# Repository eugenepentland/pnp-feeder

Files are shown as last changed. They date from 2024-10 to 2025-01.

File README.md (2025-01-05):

# Pick and Place Feeder Project

Prototype Feeder Advancing

## Overview
The aim of this project is to design a low cost powered and addressable pick and place feeder. Other pnp feeders exist but didn't meet my design requirements or were too expensive to justify having 100+ feeders.

This project aims to solve these challenges by providing an easy-to-use, modular, and affordable feeder system that can be used with both the Neoden 4 and Lumen PnP machines.

## Design Goals

1. **Compatibility**
   - Design a powered, pick and place feeder compatible with Neoden 4 and OpenPNP machines.
   - Support component sizes down to 0201.

2. **Low Cost**
   - Keep the BOM cost per feeder unit under $10 to make the solution accessible and affordable for hobbyists and small manufacturers.

3. **Fast Production**
   - Limit 3D printing time per unit to less than 2 hours using a standard consumer-grade 3D printer.
   - Assembly time less than 10 minutes per feeder

4. **Ease of Use**
   - Ensure quick part loading to minimize the setup time.
   - Allow preloaded cartridges for efficient part swapping, avoiding the need to load components directly into the machine.

5. **Scalability**
   - Support up to 512 feeders on a single master device to enable integration into a larger inventory system, such as with InvenTree.

## Block Diagrams

### System Block Diagram
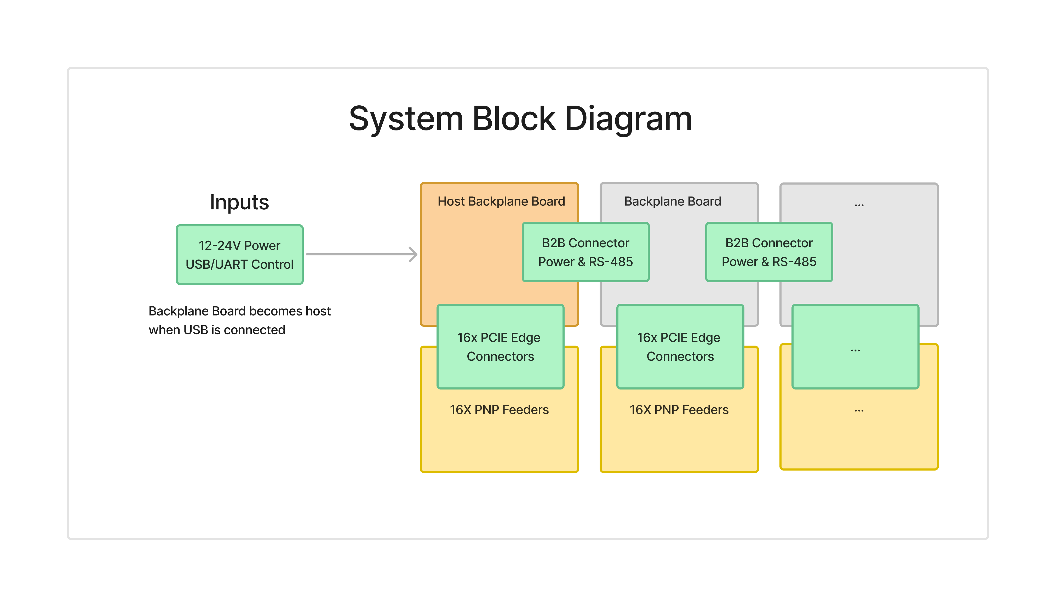
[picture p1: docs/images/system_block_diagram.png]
System Block Diagram


The system block diagram illustrates the two boards involved in the design: the feeder and the backplane board. One backplane board acts as the host, from either being connected to a PC or getting data from the host UART bus. Additional backplane boards can be attached and act as slaves to allow for up to 512 feeders from one host which sends RS-485 data and power. This scalability makes the system suitable for use as an inventory system. Power can be supplied at either 24V or 12V.

### Feeder Block Diagram
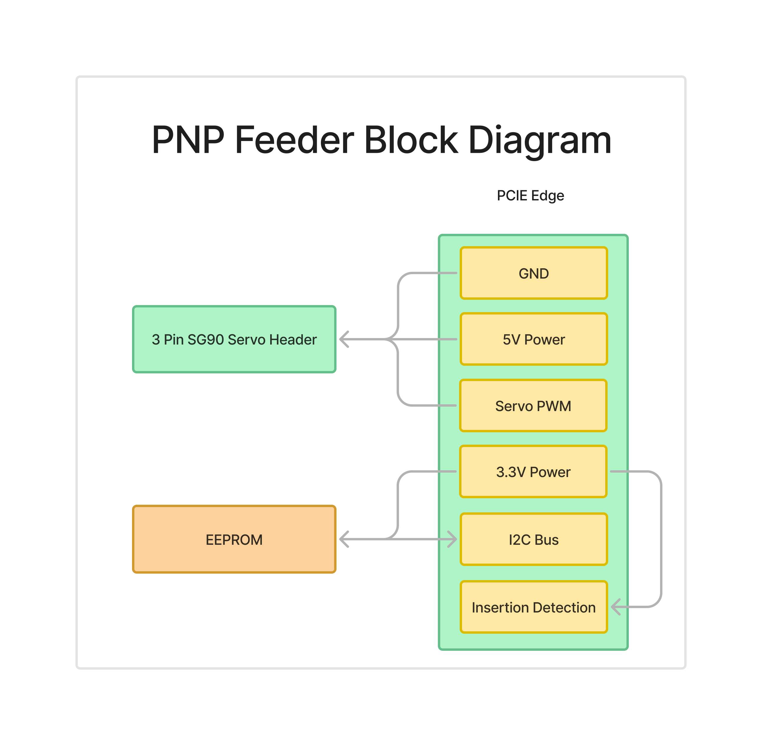
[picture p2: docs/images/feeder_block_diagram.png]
Feeder Block Diagram


The feeder block diagram shows that each feeder has a very simple board, just an EEPROM for storing MPN, quantity, feed distance and any other metadata, as well as a header for the SG90 servo motor., which controls an SG90 servo motor responsible for advancing the tape forwards. 

## Progress Checklist

1. [X] System Level Block Diagram
2. [X] Feeder Block Diagram
3. [X] Backplane Block Diagram
4. [X] MVP Feeder Hardware Prototype
5. [X] Feeder Positioning Accuracy Testing
6. [X] Feeder Lifespan Testing
7. [ ] Neoden 4 Data Packet Reverse Engineering
8. [X] Mechanical Footprint Design
9. [X] Feeder PCB Layout
10. [X] Feeder Schematic
11. [X] Backplane PCB Layout
12. [X] Backplane PCB Schematic
13. [ ] Order PCBs and test
14. [ ] System Integration and Testing
15. [ ] Support OpenPNP

## Contributing
Contributions are welcome! Please check the progress checklist above and feel free to open issues or submit pull requests for any ongoing tasks.

## License
This project is licensed under the MIT License - see the LICENSE file for details.

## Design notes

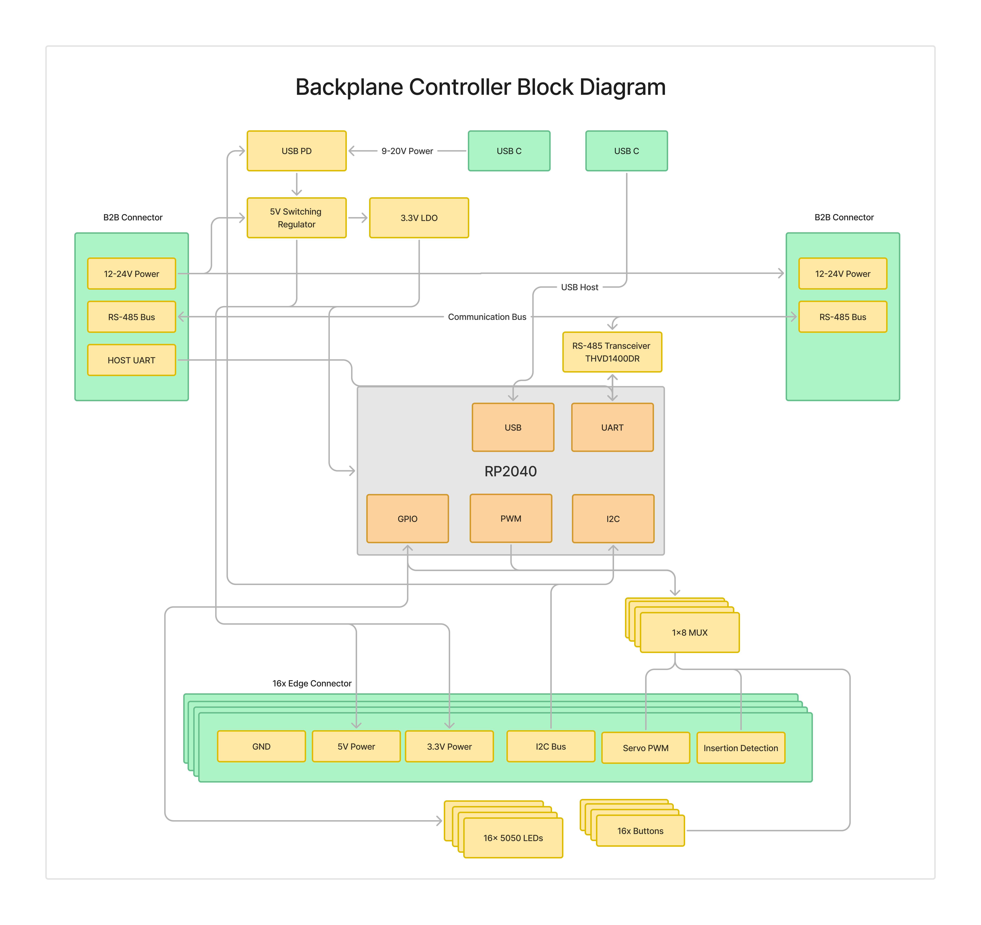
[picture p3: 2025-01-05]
docs/images/backplane_block_diagram.png

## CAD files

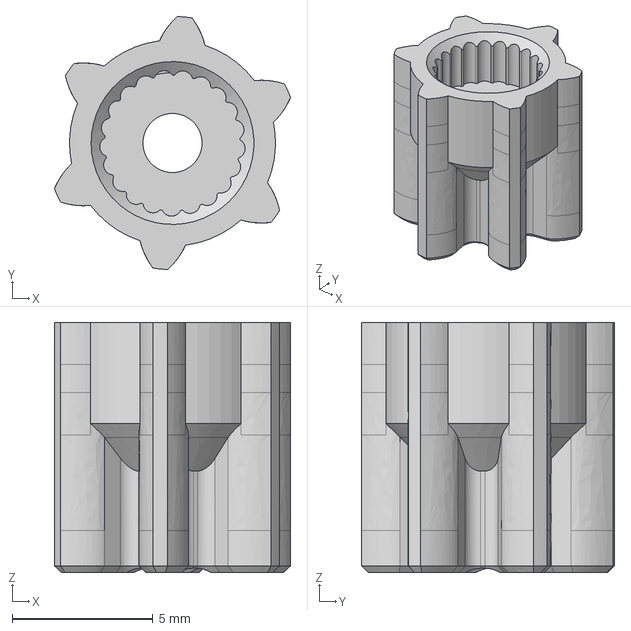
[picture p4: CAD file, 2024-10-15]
cad/step/Spur Gear.step
8.40 x 8.99 x 8.90 mm

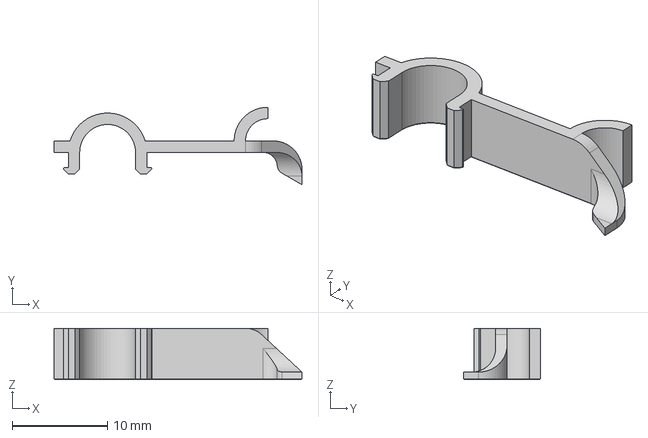
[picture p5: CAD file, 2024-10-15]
cad/step/Backfeed Preventer.step
26.1 x 8.14 x 5.40 mm

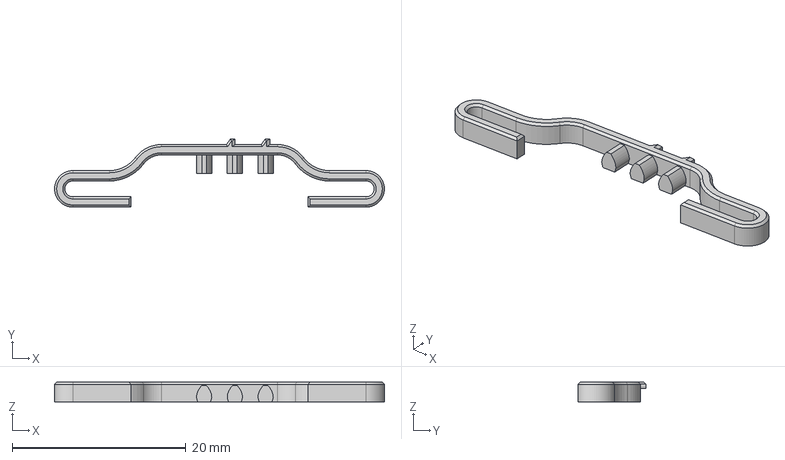
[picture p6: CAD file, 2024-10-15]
cad/step/Rack.step
37.9 x 7.85 x 2.28 mm

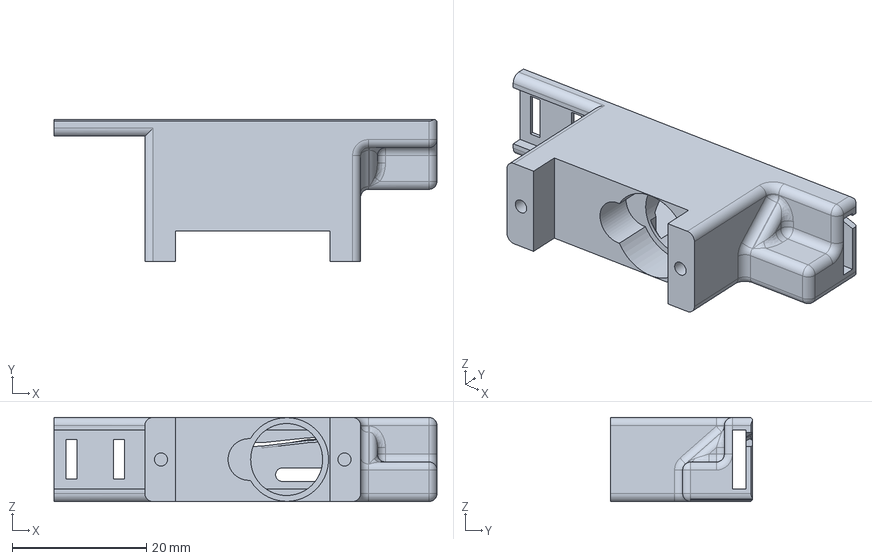
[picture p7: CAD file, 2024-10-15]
cad/step/Body.step
57.0 x 21.2 x 12.5 mm

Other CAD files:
cad/stl/Backfeed Preventer.stl
cad/stl/Body.stl
cad/stl/Rack.stl
cad/stl/Spur Gear.stl

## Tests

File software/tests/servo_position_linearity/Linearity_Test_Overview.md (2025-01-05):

# Linearity Measurement Test for X-Axis Motion

## Overview

This test is designed to **evaluate the linearity of the X-axis motion** in a pick-and-place feeder system. By using an **SG90 servo motor** coupled with a **rack and pinion mechanism**, the system pushes tape along the X-axis. Ensuring linear motion is crucial for the precision and reliability of automated placement tasks.

## Test Purpose

- **Assess Linearity**: Determine how consistently the servo motor translates its rotational steps into linear movement along the X-axis.
- **Identify Deviations**: Detect any inconsistencies or non-linear behaviors in the motion mechanism that could affect placement accuracy.

## Test Methodology

1. **Servo Control**:
   - The SG90 servo motor is commanded to move in incremental steps.
   - Each step corresponds to a specific displacement of the rack and pinion, pushing the tape forward.

2. **Image Capture**:
   - A camera monitors the tape's position along the X-axis.
   - At each servo step, an image is captured to determine the tape's exact position.

3. **Data Collection**:
   - The system processes the captured images to calculate the X-axis position in millimeters.
   - Positions are logged alongside the corresponding servo step indices for analysis.

4. **Stability Check**:
   - Multiple images are taken at each step to ensure reliable and consistent position measurements.
   - Only stable and repeatable measurements are recorded.

## Result Charts Explained

### 1. **X Position vs. Servo Index**

- **Purpose**: Visualizes how the X-axis position changes with each servo step.
- **What to Look For**:
  - **Straight Line**: Indicates perfect linearity; each servo step results in a consistent displacement.
  - **Curvature or Deviations**: Suggests non-linear behavior, which may require calibration or mechanical adjustments.

### 2. **Median X Position with Standard Deviation**

- **Purpose**: Shows the central tendency and variability of the X-axis positions at each servo step.
- **What to Look For**:
  - **Median Line**: Represents the typical X-position for each servo step.
  - **Error Bars (Standard Deviation)**: Indicate the consistency of measurements. Smaller error bars reflect higher precision.

### 3. **Linear Regression Fit**

- **Purpose**: Assesses the relationship between servo steps and X-axis displacement.
- **What to Look For**:
  - **Slope**: Determines how much the X-position changes per servo step. A consistent slope confirms linear motion.
  - **R-squared Value**: Measures how well the data fits the linear model. Values close to 1 indicate strong linearity.

### 4. **Steps Required for Desired Movement**

- **Purpose**: Calculates the number of servo steps needed to achieve a specific linear displacement (e.g., 2 mm).
- **What to Look For**:
  - **Steps per mm**: Helps in setting precise movements for the feeder.
  - **Annotation on Plot**: Provides a quick reference for operational adjustments.

## Interpreting the Results

- **High Linearity**:
  - **Straight Median Line** with **minimal deviation**.
  - **High R-squared Value** (close to 1).
  - **Consistent Steps per mm** indicating reliable motion control.

- **Low Linearity**:
  - **Curved or Irregular Median Line** with **significant deviations**.
  - **Lower R-squared Value**, indicating poor fit to a linear model.
  - **Inconsistent Steps per mm**, which may lead to placement inaccuracies.

## Conclusion

This high-level test effectively measures the **linearity and precision** of the X-axis motion in a servo-driven pick-and-place system. By analyzing the resulting charts, one can determine the reliability of the mechanical setup and make necessary adjustments to ensure accurate and consistent operation.

Regularly performing this test helps maintain the quality and efficiency of automated placement tasks, ensuring that each movement is both precise and predictable.

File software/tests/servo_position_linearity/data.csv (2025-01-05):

x_position_mm | index
6.9222222222222225 | 900
7.0 | 895
7.0 | 890
7.0 | 885
7.0 | 880
7.0 | 875
7.0 | 870
6.961111111111111 | 865
7.0 | 860
6.961111111111111 | 855
7.0 | 850
7.0 | 845
6.961111111111111 | 840
7.0 | 835
7.0 | 830
7.0 | 825
7.0 | 820
7.0 | 815
6.9222222222222225 | 810
7.038888888888889 | 785
7.116666666666667 | 780
7.116666666666667 | 775
7.155555555555556 | 770
7.116666666666667 | 765
7.194444444444445 | 760
7.272222222222222 | 750
7.388888888888889 | 730
7.466666666666667 | 720
7.583333333333333 | 710
7.622222222222223 | 705
7.622222222222223 | 700
7.622222222222223 | 695
7.661111111111111 | 690
7.622222222222223 | 685
7.7 | 680
7.7 | 675
7.738888888888889 | 670
7.855555555555556 | 665
7.894444444444445 | 655
7.894444444444445 | 650
7.933333333333334 | 645
8.011111111111111 | 640
8.05 | 635
8.088888888888889 | 630
8.088888888888889 | 625
8.127777777777778 | 610
8.127777777777778 | 605
8.127777777777778 | 600
8.322222222222223 | 575
8.4 | 555
8.438888888888888 | 550
8.477777777777778 | 545
8.594444444444445 | 510
8.633333333333333 | 505
8.75 | 495
8.711111111111112 | 490
8.827777777777778 | 480
8.78888888888889 | 475
8.905555555555555 | 470
8.866666666666667 | 465
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

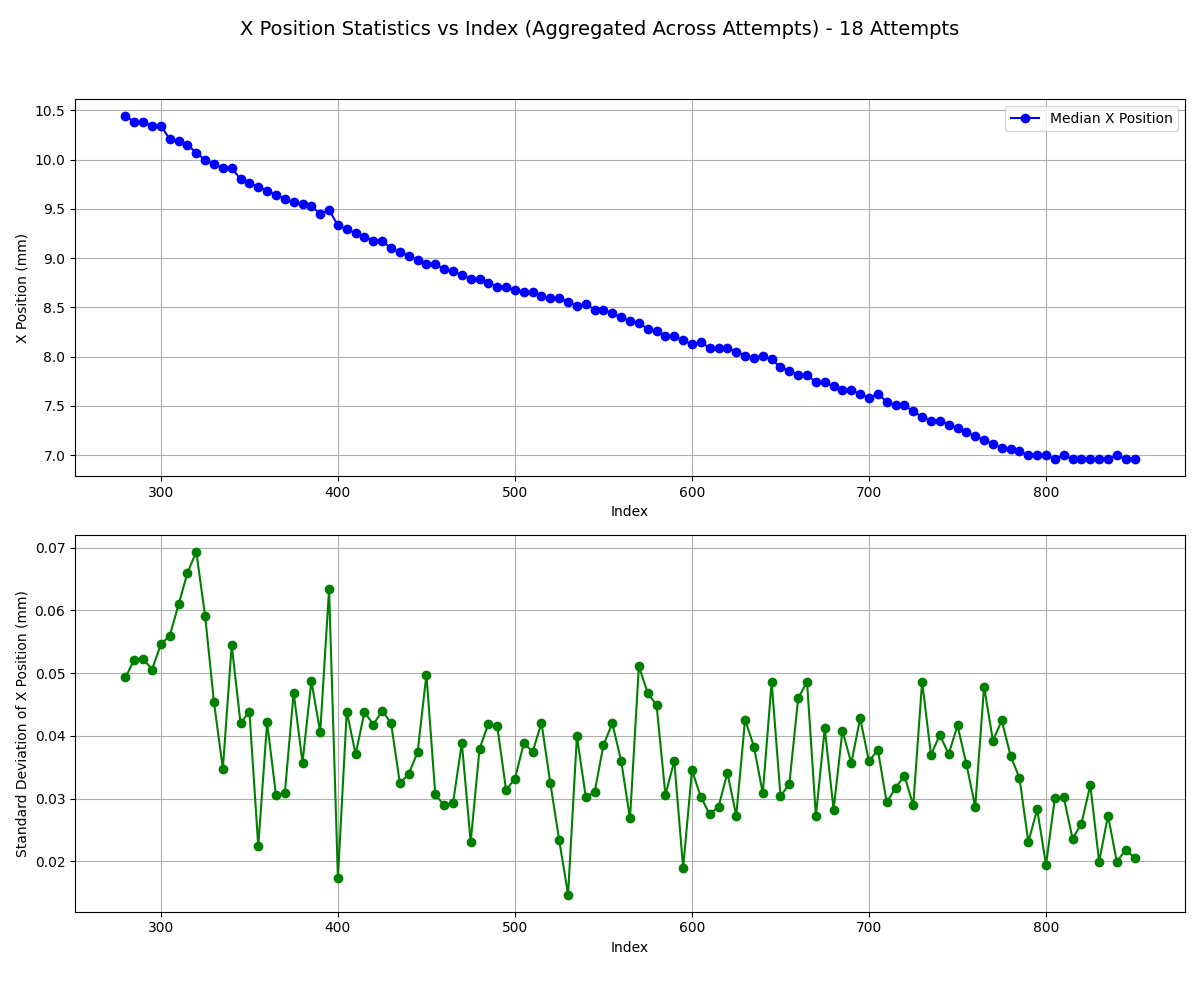
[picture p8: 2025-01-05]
software/tests/servo_position_linearity/aggregated_median_std_dev_vs_index_plot_attempt_18.png

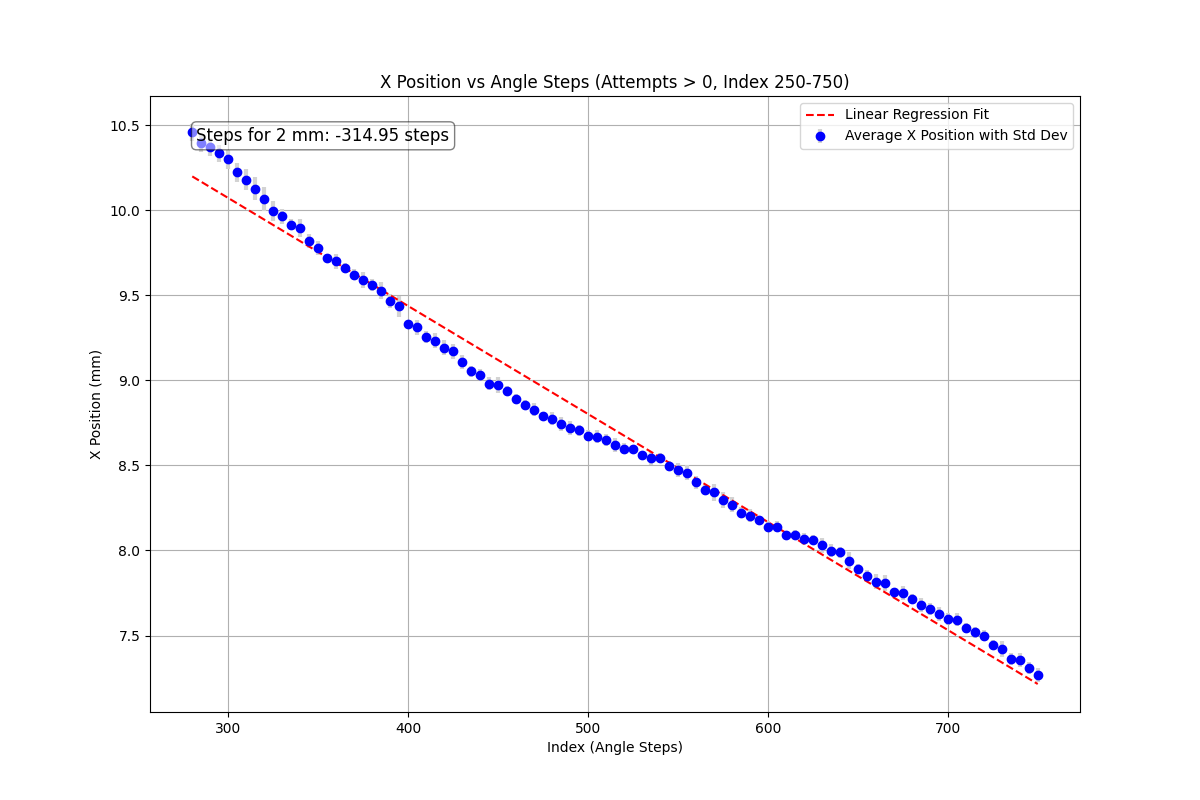
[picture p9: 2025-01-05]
software/tests/servo_position_linearity/x_position_analysis_attempt_0_index_250_750.png

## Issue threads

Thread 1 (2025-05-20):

How to replicate？

ChangYanChu, 2025-05-20:
Hi, this project is really great. I want to know the current progress. It seems that I haven't found the control PCB of Feida and more project documents. How can we replicate this project?

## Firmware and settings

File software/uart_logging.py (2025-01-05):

import serial
import signal
import sys

def signal_handler(sig, frame):
    print("\nCtrl+C detected. Closing serial connection...")
    if ser and ser.is_open:
        ser.close()
    sys.exit(0)

if __name__ == "__main__":
    # Set up signal handler for Ctrl+C
    signal.signal(signal.SIGINT, signal_handler)

    ser = None  # Define `ser` outside the try block for access in the signal handler
    
    try:
        # Connect to the serial port
        ser = serial.Serial(
            port='/dev/ttyACM0',  # Replace with your serial port
            baudrate=115200,
            parity=serial.PARITY_NONE,
            stopbits=serial.STOPBITS_ONE,
            bytesize=serial.EIGHTBITS,
            timeout=2  # Adjust timeout as needed
        )
        print("Connected to serial port. Reading data...")

        # Continuously read data from the serial port
        while True:
            if ser.in_waiting > 0:  # Check if data is available
                data = ser.read(ser.in_waiting).decode('utf-8', errors='ignore')  # Decode as UTF-8, ignoring errors
                print(data, end='')  # Print the data without adding extra newlines

    except Exception as e:
        print(f"Error: {e}")

    finally:
        # Ensure the serial connection is closed
        if ser and ser.is_open:
            print("Closing serial connection...")
            ser.close()

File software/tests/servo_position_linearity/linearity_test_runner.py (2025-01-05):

import os
import time
import math
import csv
import serial
import cv2
import numpy as np
import pandas as pd
import matplotlib.pyplot as plt

import software.tests.servo_position_linearity.messages as messages  # Assuming this is a custom module


# Constants
IMAGE_SAVE_DIR = "measured_images"
SINGLE_IMAGE_FILENAME = os.path.join(IMAGE_SAVE_DIR, "current_view.png")
BLURRED_IMAGE_FILENAME = os.path.join(IMAGE_SAVE_DIR, "blurred_view.png")
GRAY_IMAGE_FILENAME = os.path.join(IMAGE_SAVE_DIR, "gray_view.png")

CSV_FILENAME = "data.csv"
FIELDNAMES = ["x_position_mm", "index"]  # Store x position in mm and index

CIRCLE_DIAMETER_PIXELS = 72  # Diameter in pixels
CIRCLE_DIAMETER_MM = 1.4      # Actual diameter in millimeters (update as needed)
PIXEL_TO_MM_SCALE = CIRCLE_DIAMETER_MM / CIRCLE_DIAMETER_PIXELS  # mm per pixel

# Define the Region of Interest (ROI) as a dictionary
roi = {
    "x_start": None,
    "y_start": None,
    "width": None,
    "height": None
}

def ensure_image_save_dir():
    """Ensure that the image save directory exists."""
    os.makedirs(IMAGE_SAVE_DIR, exist_ok=True)

def write_message(message, ser):
    """Serialize and send a message through the serial port."""
    data = message.serialize()
    ser.write(data)
    _ = ser.read(4)  # Read acknowledgment (if needed)

def detect_and_draw_circle(original_image, cropped_image, roi_x_start, roi_y_start):
    """
    Detect the closest circle to the center of the cropped image and draw it on the original image.
    
    Returns:
        x_position_mm (float): The x position in millimeters.
        processed_image (numpy.ndarray): The image with the detected circle drawn.
        gray (numpy.ndarray): Grayscale image.
        gray_blurred (numpy.ndarray): Blurred grayscale image.
        closest_circle (tuple): Coordinates and radius of the detected circle.
    """
    gray = cv2.cvtColor(cropped_image, cv2.COLOR_BGR2GRAY)
    gray_blurred = cv2.medianBlur(gray, 5)

    # Detect circles using HoughCircles
    circles = cv2.HoughCircles(
        gray_blurred,
        cv2.HOUGH_GRADIENT,
        dp=1,
        minDist=20,
        param1=25,
        param2=20,
        minRadius=36,
        maxRadius=38
    )

    closest_circle = None
    min_distance = float('inf')
    center_x = cropped_image.shape[1] // 2
    center_y = cropped_image.shape[0] // 2

    if circles is not None:
        circles = np.round(circles[0, :]).astype("int")
        for x, y, r in circles:
            distance = math.sqrt((x - center_x)**2 + (y - center_y)**2)
            if distance < min_distance:
                closest_circle = (x, y, r)
                min_distance = distance

        if closest_circle:
            x, y, r = closest_circle
            original_x = roi_x_start + x
            original_y = roi_y_start + y
            cv2.circle(original_image, (original_x, original_y), r, (0, 255, 0), 4)
            # Convert x position to mm
            x_position_mm = original_x * PIXEL_TO_MM_SCALE
            return x_position_mm, original_image, gray, gray_blurred, closest_circle

    return None, original_image, gray, gray_blurred, None

def capture_and_process(camera, is_first_iteration, roi):
    """
    Capture images from the camera, detect circles, and ensure stability of detection.
    
    Returns:
        calculated_x_position (float): The stable x position in millimeters.
        processed_image_for_save (numpy.ndarray): The processed image to save.
        detected_circle (tuple): Coordinates and radius of the detected circle.
    """
    attempts = 0
    max_attempts = 5
    calculated_x_position = None
    processed_image_for_save = None
    detected_circle = None

    while attempts < max_attempts:
        ret, captured_image = camera.read()
        if not ret:
            print(f"Error reading camera (attempt {attempts + 1})")
            attempts += 1
            continue

        image_height, image_width, _ = captured_image.shape

        if is_first_iteration:
            roi["x_start"] = 0
            roi["y_start"] = 0
            roi["width"] = image_width
            roi["height"] = image_height
        else:
            # Validate and adjust ROI within image bounds
            roi["x_start"] = max(0, min(roi["x_start"], image_width - roi["width"]))
            roi["y_start"] = max(0, min(roi["y_start"], image_height - roi["height"]))

        # Crop the image to the ROI
        cropped_image = captured_image[
            roi["y_start"]:roi["y_start"] + roi["height"],
            roi["x_start"]:roi["x_start"] + roi["width"]
        ]

        x_position1, processed_image1, _, _, detected_circle = detect_and_draw_circle(
            captured_image, cropped_image, roi["x_start"], roi["y_start"]
        )

        if detected_circle is not None:
            _, _, cr = detected_circle

            # Update ROI to be centered around the detected circle
            new_roi_width = int(2 * cr * 2)  # 2 times the diameter
            new_roi_height = int(2 * cr * 2)
            cx_absolute = roi["x_start"] + detected_circle[0]
            cy_absolute = roi["y_start"] + detected_circle[1]

            roi["x_start"] = max(0, int(cx_absolute - new_roi_width / 2))
            roi["y_start"] = max(0, int(cy_absolute - new_roi_height / 2))
            roi["width"] = min(new_roi_width, image_width - roi["x_start"])
            roi["height"] = min(new_roi_height, image_height - roi["y_start"])

        if x_position1 is None:
            attempts += 1
            continue

        # Capture the second image for stability check
        ret2, captured_image2 = camera.read()
        if not ret2:
            print("Error reading camera (stability check)")
            return None, None, None

        cropped_image2 = captured_image2[
            roi["y_start"]:roi["y_start"] + roi["height"],
            roi["x_start"]:roi["x_start"] + roi["width"]
        ]
        x_position2, _, _, _, _ = detect_and_draw_circle(
            captured_image2, cropped_image2, roi["x_start"], roi["y_start"]
        )

        if x_position2 is None:
            attempts += 1
            continue

        if abs(x_position1 - x_position2) < 10 * PIXEL_TO_MM_SCALE:  # Adjust threshold based on scale
            calculated_x_position = x_position1
            processed_image_for_save = processed_image1
            break
        else:
            print(f"X positions not consistent ({x_position1:.2f} mm vs {x_position2:.2f} mm), retrying...")
            attempts += 1

    if calculated_x_position is not None and processed_image_for_save is not None:
        cv2.imwrite(SINGLE_IMAGE_FILENAME, processed_image_for_save)
        print(f"Saved current view image to {SINGLE_IMAGE_FILENAME}")

    return calculated_x_position, processed_image_for_save, detected_circle
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

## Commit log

2024-10-15 reformat and added cad/design goals
    [Backfeed Preventer.step, Backfeed Preventer.stl, Body.step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]
2024-10-16 updated feeder bd to included neoden4 connector
2025-01-05 refactored to use drivers
2025-01-05 added software tests for linearity
    [data.csv]
2025-03-31 added control for switches, insertion detection and button presses
2025-03-31 updated LED color to be packed struct
